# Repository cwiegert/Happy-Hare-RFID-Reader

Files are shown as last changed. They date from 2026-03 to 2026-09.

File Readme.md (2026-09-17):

$$\Huge{\color{red}\textsf{Thanks for landing here!}}$$

$$\LARGE{\color{red}\textsf{The Happy Hare add-on is now base functionality in Happy Hare v4.}}$$

$$\LARGE{\color{red}\textsf{Please go to https://github.com/moggieuk/Happy-Hare for the new install.}}$$

<h3 align="center"><a href="https://github.com/moggieuk/Happy-Hare">➡️ Go to Happy Hare v4 &mdash; github.com/moggieuk/Happy-Hare</a></h3>

> [!CAUTION]
> **This repository is no longer maintained.**
>
> Every capability this add-on provided has been migrated into **Happy Hare v4** as
> a base option. There is nothing here you need any more — install Happy Hare v4
> instead: 
>
> No further fixes, features, or compatibility updates will be published here.
> The content below is kept only as a historical reference for existing installs.
Edit the readme to state this is repo is no longer maintained, and the recommended approach for deploymnet is Happy Hare v4 .   document the capabilitiees have all been migrated to base options in Happy Hare v4.   

_____________________________________________________________________
_____________________________________________________________________
_____________________________________________________________________
> [HISTORICAL NOTES and INSTRUCTIONS]

$$\LARGE{\color{red}\textsf{This repository is not actively maintained}}$$

## Recommended Deployment: Happy Hare v4

**Install [Happy Hare v4](https://github.com/moggieuk/Happy-Hare) and enable NFC/RFID
there.** Do not start a new install from this repository.

NFC spool identification is no longer an add-on that has to be layered on top of
Happy Hare. It ships as part of Happy Hare v4 and is configured through Happy Hare's
own options, so a new install needs one project, one config, and one updater instead
of a plugin tracking a moving host.

### Capabilities Migrated to Happy Hare v4 Base Options

Everything in the table below is now native Happy Hare v4 functionality. Consult the
[Happy Hare v4 documentation](https://github.com/moggieuk/Happy-Hare) for the current
option names and setup steps — the configuration keys documented further down this
page belong to this retired add-on and do not apply to v4.

| Capability this add-on provided | Status in Happy Hare v4 |
|---|---|
| Per-lane NFC readers on lane/EMU MCUs | Base option |
| Single shared reader inside the MMU body (tap before loading) | Base option |
| Hybrid per-lane plus shared reader operation | Base option |
| NFC reader as a virtual homing endstop for scan-jog | Base option |
| Scan-jog spool rotation to find the tag during preload | Base option |
| PN532, PN7160, RC522, and PN5180 reader support | Base option |
| Spoolman UID lookup and gate-map assignment | Base option |
| Rich tag parsing (NTAG/Type-2, MIFARE Classic, SLIX2/ISO15693) | Base option |
| Vendor tag formats (Bambu, Creality, ELEGOO, Anycubic, QIDI, TigerTag, OpenSpool, OpenTag3D, OpenPrintTag) | Base option |
| Spoolman auto-create from tag metadata | Base option |
| Per-gate NFC LED effects | Base option |

### Migrating an Existing Install

1. Read the [Happy Hare v4](https://github.com/moggieuk/Happy-Hare) install and NFC
   documentation first — v4 owns this functionality now, and its options differ from
   the ones described below.
2. Run this repository's `uninstall.sh` to remove the add-on's Klipper extras,
   generated config, and macro includes.
3. Install or update Happy Hare v4 and enable its NFC/RFID options.
4. Re-flash any MCU hosting an NFC reader from the same Klipper checkout, then
   restart Klipper and confirm every MCU reconnects.

---

## Archived Reference

Everything from here down documents the retired add-on. It is preserved for anyone
maintaining an existing installation and is **not** a guide for new deployments.

## Happy Hare RFID/NFC Reader (retired add-on)

NFC spool identification for Happy Hare. Use one NFC reader on each EMU lane, one shared reader inside the MMU body, or both. PN532 remains the default reader; PN7160, RC522, and PN5180 are available with `reader_type: pn7160`, `rc522`, and `pn5180`.

This is a system-level Klipper integration, not a plug-and-play appliance. It touches Klipper extras, Happy Hare macros, lane MCU firmware, I2C wiring, Spoolman, and optional LED effects. If you are not comfortable recovering from a Klipper config error, reflashing lane MCUs, and reading logs, expect a learning curve.

## Why This Project Is Different

Most DIY spool RFID/NFC systems put a small controller such as an ESP32 near the
reader and report tags over WiFi, MQTT, or another side channel. Others wire the
reader back to the host Raspberry Pi, which often means long SDA/SCL or USB runs
through the printer.

This project keeps the reader inside the MMU wiring domain. Each NFC reader is
connected directly to an existing Klipper MCU I2C bus, usually the MMU board or
the per-lane board inside the MMU. Klipper talks to that MCU, and the plugin
integrates the result with Happy Hare and Spoolman.

Practical hardware choices:

- **EMU / one board per lane:** per-lane readers are a natural fit. Each lane has
  its own MCU/I2C bus, so PN532 and PN7160 are both valid choices.
- **Other B-style multi-material systems with one MMU board:** PN7160 is usually
  the better choice for multiple readers on one bus because it has four
  selectable I2C addresses (`40-43` / `0x28-0x2B`). That matches many four-color
  MMU layouts.
- **Single shared reader:** PN532, PN7160, RC522, or PN5180 can be mounted
  inside the MMU body and used as a tap-before-loading reader. PN5180 is the
  SPI option when SLIX2 (ISO15693/Type-5) support is required.

For EMU installations, [`NFC Mounting Bracket/`](NFC%20Mounting%20Bracket/)
contains the printable STL and editable STEP source for the NFC-reader LED holder.

## Virtual Endstop — How Scan-Jog Finds the Tag

Per-lane installs register each lane's NFC reader as a real Klipper/Happy Hare
homing endstop (`mmu_nfc_endstop.py`, `[mmu_nfc_endstop laneN]`) — no extra
hardware or wiring, it borrows the reader the matching `[nfc_gate laneN]`
section already owns. When scan-jog searches for the tag, the forward search
is a genuine Klipper homing move (`ENDSTOP=nfc_lane<N>`) that stops the
instant the tag is detected, instead of jogging a fixed chunk and polling
afterward and hoping the tag was somewhere in that chunk. This is generated
automatically for every enabled lane by `install.sh` — there is nothing extra
to configure. See [How It Works](docs/shared/how-it-works.md) for the full
scan loop and [Configuration Reference](docs/shared/configuration.md) for the
`[mmu_nfc_endstop laneN]` keys.

The same configuration supports Happy Hare V3 and V4. The plugin registers
the software endstop on V3's shared gear rail or on the V4 drive selected by
the reader's `mmu_gate`. Lane and endstop section names are only labels; the
`nfc_gate` reference and `mmu_gate` value provide the actual binding, including
multi-unit installations.

## Operating Modes

| Mode | Hardware | Best For | Flow |
|---|---|---|---|
| Per-lane readers | One NFC reader per EMU gate/lane MCU (default PN532; PN7160, RC522, or PN5180 supported) | Automatic spool identification during lane preload | Load spool -> HH parks filament -> NFC scan-jog rotates spool -> Spoolman lookup -> HH gate map |
| Shared reader | One NFC reader mounted inside the MMU body (PN532, PN7160, RC522, or PN5180) | Fewer readers, manual tap before loading | Tap tag -> spool staged -> load any gate -> HH pregate preload -> staged spool assigned |
| Hybrid | Per-lane readers plus shared reader | Normal lanes with per-lane readers, plus shared/bypass workflows | Lane readers handle scan-jog; shared reader stages tapped spools for preload |

The shared reader can stage only a real Spoolman spool ID. UID lookup, embedded spool IDs, and auto-created Spoolman records work. Metadata-only tags without a Spoolman spool ID cannot be staged for Happy Hare preload.

## Requirements

- Voron/EMU setup running the [igiannakas IG-dev branch of Happy Hare](https://github.com/igiannakas/Happy-Hare/tree/IG-dev), which provides `variable_user_post_preload_extension`
- One Klipper MCU per filament lane for per-lane reader installs, or one MCU hosting the shared NFC reader
- Supported NFC reader hardware configured for its bus
- Hardware I2C or SPI bus on the MCU hosting the NFC reader
- Klipper version requirements:
  - Strongly recommended: use the latest Klipper on the host and every MCU
    hosting an NFC reader. The NFC drivers use Klipper's newer low-level
    `i2c_transfer` / `i2c_bus_status` path so bus errors such as `START_NACK`
    can be handled on the host side instead of turning reader faults into
    Klipper shutdowns.
  - If checking an older install, it should be newer than upstream commit
    `6bbc9069` (`bus: Note mcu code deprecation if missing i2c_transfer`,
    Feb 24, 2026 on GitHub).
  - After updating Klipper, rebuild and flash every MCU hosting an NFC reader.
- Spoolman reachable from the Pi
- NFC tags on spools: NTAG213/215/216, MIFARE Classic, or supported rich-tag formats
- Lane MCU firmware rebuilt from the same Klipper checkout as the host

## Happy Hare V4 Compatibility Notes (retired add-on)

Happy Hare v4 can run the post-preload hook while the MMU reports
`action=checking`. For automatic gate-status polling, NFC treats `checking` as
scan-safe only when the detected Happy Hare major version is 4 or newer. For
the post-preload hook, `_NFC_SCAN_JOG_PRELOAD` sends
`NFC GATE=<n> JOG_SCAN=1 SOURCE=AUTO`; that trusted hook path uses the same
version-aware scan-safe check: Happy Hare v4 accepts `action=idle` or
`action=checking`; Happy Hare v3/pre-v4 and unknown versions accept only
`action=idle`. Manual or console `JOG_SCAN=1` commands without `SOURCE=AUTO`
stay conservative and always require `action=idle`.

Happy Hare V4 also validates `MMU_SET_LED` effect names against its configured
operation effects. NFC therefore starts generated `[mmu_led_effect]` instances
directly on V4, while keeping the existing public `MMU_SET_LED` path on V3.
No LED configuration changes are required: define NFC effects with
`define_on: gates` (or `define_on: gates, exit`) as usual.

Supported readers:

| Reader | `reader_type` | Bus / address | Notes |
|---|---|---|---|
| PN532 | `pn532` | `36` (`0x24`) | Default reader and documented PN532 wiring path |
| PN7160 | `pn7160` | `40-43` (`0x28-0x2B`) | Supports NTAG/Type2, ISO15693/Type5, and authenticated Bambu/MIFARE reads |
| RC522 | `rc522` | SPI (`cs_pin` + `spi_bus`/software SPI pins) | UID lookup, NTAG/Type-2 rich reads, and authenticated MIFARE/Bambu reads; no ISO15693 |
| PN5180 | `pn5180` | SPI (`cs_pin`, `spi_bus`/software SPI pins, `busy_pin`, `reset_pin`) | ISO14443A/NTAG, authenticated MIFARE/Bambu, and SLIX2 (ISO15693/Type-5) reads; see the SLB nine-wire wiring guide |

Supported tag formats:

| Tag / data path | PN532 | PN7160 | RC522 | PN5180 | Notes |
|---|---:|---:|---:|---:|---|
| Spoolman UID lookup | Yes | Yes | Yes | Yes | Default path. The tag only needs a readable factory UID registered in Spoolman's extra field. |
| NTAG / NFC Type 2 rich tags | Yes | Yes | Yes | Yes | NDEF text/URI/MIME/JSON payloads, OpenSpool, OpenTag3D, TigerTag, OpenPrintTag text-compatible payloads, and several manufacturer binary tags. |
| MIFARE Classic rich tags | Yes | Yes | Yes | Yes | Bambu, QIDI Box, and Creality CFS all require `tag_parsing: True` and `bambu_reads: True`. Bambu's own keys and Creality's UID-derived Key B both additionally require `pycryptodome`; QIDI uses a factory-default-key fallback that needs no extra dependency (see [Configuration Reference](docs/shared/configuration.md#tag-data-parsing)). |
| SLIX2 / ISO15693 Type 5 rich tags | No | Yes | No | Yes | Current Type-5 rich-read path is for SLIX2 tags. Its payload enters the normal parser and is not limited to OpenPrintTag. Official OpenPrintTag antenna size is best suited to a shared reader; per-lane use needs hardware testing. |

The vendored parser currently recognizes Bambu Lab, ELEGOO, Anycubic ACE,
TigerTag, Creality CFS/K1/K2, QIDI Box, SimplyPrint/QIDI URL tags, OpenTag3D,
OpenSpool, OpenPrintTag, and generic NDEF JSON filament records. See
[Spoolman Integration](docs/shared/spoolman-integration.md) for format details
and auto-create behavior. Bambu, TigerTag/TigerTag+, and tested Creality
CFS/K1/K2 rich tags also expose parser-derived same-spool `spool_identity`
values for scan-jog left-neighbor interference handling.

## Documentation

| Guide | Purpose |
|---|---|
| [NFC Reader Wiring](docs/i2c-nfc/wiring.md) | PN532, PN7160, RC522, and PN5180 wiring; includes the PN5180 SLB nine-wire guide |
| [Install & Uninstall](docs/shared/install-uninstall.md) | Installer behavior, includes, updates, removal |
| [First-Time Setup](docs/i2c-nfc/setup.md) | Configure Spoolman, lane hardware, first verification |
| [Shared Reader](docs/shared/shared-reader.md) | Shared-reader workflow, hook wiring, commands, LED behavior |
| [Configuration Reference](docs/shared/configuration.md) | Every config key, defaults, inheritance rules |
| [Commands & Macros](docs/shared/klipper-functions.md) | User commands, shared commands, callback macros |
| [Message Definitions](docs/shared/message_definition.md) | Console output and matching `nfc_reader.log` entries |
| [Spoolman Integration](docs/shared/spoolman-integration.md) | Extra field setup, UID registration, lookup behavior |
| [Troubleshooting](docs/i2c-nfc/troubleshooting.md) | Startup errors, reader failures, tag lookup issues |
| [How It Works](docs/shared/how-it-works.md) | Boot sequence, poll flow, scan-jog, dispatch layers |
| [Expert I2C Debugging](docs/shared/expert-low-level-i2c-debugging.md) | Low-level PN532 probe commands |

## Quick Install

Before installing, rebuild and flash Klipper firmware on every MCU that will host an NFC reader. Host and MCU firmware version mismatches produce I2C failures that look like wiring or reader problems.

```bash
cd ~
git clone https://github.com/cwiegert/Happy-Hare-RFID-Reader.git rfid-reader
cd ~/rfid-reader
bash install.sh
```

Beta cutover note: if an old `~/emu-nfc-reader` install exists, the installer prompts before backing it up/removing it and continuing with a fresh `~/rfid-reader` install.

The interactive installer runs once. Normal updates are installed afterward from Moonraker's web interface in Mainsail or Fluidd. If installer-owned links or integration files are damaged, run `bash install.sh -r`; repair does not rewrite user NFC settings. To change the configured reader layout or settings later, run `bash install.sh --reconfigure`; the wizard backs up the complete NFC configuration before applying changes.

The installer adds the matching includes to `printer.cfg` in this order.

Per-lane readers:

```ini
[include nfc/nfc_reader.cfg]
[include nfc/nfc_macros.cfg]
[include nfc/nfc_reader_hw.cfg]
```

Shared-reader-only:

```ini
[include nfc/nfc_reader.cfg]
[include nfc/nfc_macros.cfg]
[include nfc/nfc_reader_shared.cfg]
```

Hybrid:

```ini
[include nfc/nfc_reader.cfg]
[include nfc/nfc_macros.cfg]
[include nfc/nfc_reader_hw.cfg]
[include nfc/nfc_reader_shared.cfg]
```

The installer sets Spoolman in `~/printer_data/config/nfc/nfc_reader.cfg`; verify the selected value after installation:

```ini
[nfc_gate]
spoolman_url:      auto
spoolman_rfid_key: rfid_tag
```

Choose the Happy Hare post-preload hook that matches the reader layout:

```ini
[gcode_macro _MMU_SEQUENCE_VARS]
# Shared reader only:
variable_user_post_preload_extension: '_NFC_SHARED_PRELOAD'

# Per-lane and shared readers together:
# variable_user_post_preload_extension: '_NFC_HYBRID_PRELOAD'
```

Restart Klipper and run the doctor:

```bash
sudo systemctl restart klipper
```

```gcode
NFC_DOCTOR
NFC_STATUS
```

## Common Commands

```gcode
NFC_HELP                                      ; show normal command help
NFC_HELP ADVANCED=1 CALLBACKS=1 LOW_LEVEL=1  ; show the full command set
NFC_DOCTOR                                   ; check common config/setup problems
NFC_STATUS                                   ; show every configured lane/shared reader
NFC_REGISTER UID=04A1B2C3D4 SPOOL_ID=123     ; link a known UID to an existing Spoolman spool
NFC_LED_TEST ALL=1 CYCLES=2                  ; chase-test lane tag-read LEDs on all enabled lanes
NFC GATE=0 INIT=1                            ; re-run reader init on one lane reader
NFC GATE=0 SCAN=1                            ; raw UID scan, no Spoolman/HH dispatch
NFC GATE=0 LED_TEST=1 CYCLES=2               ; test lane tag-read LED on one gate
NFC GATE=0 POLL=1                            ; read, resolve, and dispatch once
NFC GATE=0 JOG_SCAN=1                        ; run scan-jog manually; blocked if HH gate is empty
NFC GATE=0 READ=1                            ; start lane background polling
NFC GATE=0 READ=0                            ; stop lane background polling
NFC_SHARED STATUS=1                          ; show shared-reader state
NFC_SHARED READ=1                            ; start shared-reader polling
NFC_SHARED REPLACE=1                         ; discard staged shared spool and scan another
NFC_SHARED CANCEL=1                          ; cancel staged shared spool
```

## Key Defaults

These are the defaults shipped in `config/nfc_reader.cfg`:

| Setting | Default | Notes |
|---|---:|---|
| `startup_polling` | `-1` | Lane polling is manual by default; post-preload scan-jog does not need it |
| `poll_interval` | `10` | Per-lane background poll interval in seconds |
| `absent_threshold` | `3` | Missed polls before a removal event |
| `scan_enabled` | `False` | Disables automatic gate-status scan-jog trigger; manual/hook `JOG_SCAN` still works |
| `scan_jog_mm` | `150.0` | Logical scan chunk divided into three stopped-position substeps |
| `scan_jog_max` | unset | Optional fixed scan-jog travel limit; leave unset to use the lane Bowden length |
| `scan_reads_per_position` | `1` | Reads per stopped scan position |
| `scan_poll_interval` | `0.25` | Read spacing during scan-jog and shared-reader polling cadence |
| `scan_motion_mode` | `continuous` | `continuous` homes the forward search against the lane's virtual NFC endstop, stopping the instant the tag is detected; `stopped` keeps blocking substep reads |
| `scan_continuous_step_mm` | `150.0` | Continuous-mode forward chunk size. Rich reads use the observed UID hit-window center, so this no longer needs to be kept small for rich-tag positioning |
| `scan_continuous_speed` | `200.0` | Continuous-mode gear move speed |
| `scan_continuous_accel` | `2000.0` | Continuous-mode gear move acceleration |
| `scan_continuous_poll_interval` | `0.05` | In-flight NFC read cadence while a continuous chunk is estimated to be moving |
| `debug` | `2` | Warnings and errors in `nfc_reader.log` |
| `console_output` | `False` | Keep routine NFC logs out of the console |

To try continuous scan-jog:

```ini
[nfc_gate]
scan_motion_mode: continuous
scan_continuous_step_mm: 150.0
scan_continuous_speed: 200.0
scan_continuous_accel: 2000.0
scan_continuous_poll_interval: 0.05
```

Continuous mode preserves the existing tag-found flow: the read-light effect
plays for about 0.1 second, then NFC rewinds and dispatches the cached tag/spool
action just like stopped mode.
If a UID is found during motion, continuous mode waits for the current chunk to
finish and checks Spoolman first. If rich tag parsing is still needed, NFC
recenters to the observed UID hit-window center before running rich parsing and
the normal rich-read retry sweep.

Set `enabled: False` on a `[nfc_gate laneN]` or `[nfc_gate shared]` section to keep the config block in place without initializing hardware or registering commands for that reader.

## MCU Firmware Warning

The NFC reader driver talks to firmware running on the MCU, not only to Klipper on the Pi. After updating Klipper, rebuild and flash every lane/shared MCU that hosts an NFC reader before debugging NFC.

Recommended update order:

```text
1. Update the Klipper host checkout.
2. Build MCU firmware from that same checkout.
3. Flash every MCU that hosts an NFC reader.
4. Restart Klipper.
5. Confirm all MCUs reconnect before testing NFC.
```

When host and MCU firmware are out of sync, common symptoms include reader init failures, `i2c_read_response` timeouts, and other devices on the same I2C bus failing unexpectedly.

## License

Copyright (C) 2026 WoodWorker.
Licensed under [GNU General Public License v3.0 or later](https://www.gnu.org/licenses/gpl-3.0.html).
See [LICENSE](LICENSE) for the full terms.

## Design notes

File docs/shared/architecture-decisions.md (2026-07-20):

# Architecture Decisions

[← Back to README](../../Readme.md)

---

This document captures the design decisions made while building the PN532 I2C path, including the reasoning and trade-offs behind each choice. It is meant to explain *why* the system is structured the way it is — so that future changes can be made with the context that drove the original decisions.

---

## Decision: Strict Layer Ownership

**What we decided:** Each layer owns exactly one responsibility and may not reach across its boundary into another layer's domain.

| Layer | Owns | Explicitly does not own |
|---|---|---|
| `PN532Driver` | PN532 wire protocol, I2C frames, UID extraction | Spoolman, gate policy, Happy Hare commands |
| `SpoolmanClient` | UID → spool record lookup and cache | Gate state, lane assignment, MMU commands |
| `NFC_Manager` | Gate state machine, changed/removed decisions, macro dispatch | PN532 protocol details |
| `nfc_macros.cfg` | Happy Hare-facing GCode calls | NFC bus reads, Spoolman HTTP requests |

**Why:** The alternative was a flat design where one module reads the tag, queries Spoolman, and calls `MMU_GATE_MAP`. We rejected this because it creates a single module that breaks for three independent reasons: hardware issues, Spoolman API changes, and Happy Hare version differences. Each layer now has a single reason to change.

**The boundary that matters most:** `SpoolmanClient` never calls Happy Hare. `PN532Driver` never calls Spoolman. NFC_Manager is the only module that sees both a UID and a gate assignment, and it dispatches a macro rather than calling Happy Hare directly.

---

## Decision: Tags Are Read-Only — UID Lookup Only

**What we decided:** The system reads the factory UID only. Tags are never written to. The UID is stored as a Spoolman extra field on the spool record.

**Why we rejected writing tags:** Writing tag payload data would require:
- A tag format standard (which format? which pages? how versioned?)
- A tag programming workflow for users
- Handling format mismatches on old tags after upgrades
- Dealing with write failures and partially-written tags

The UID approach requires none of this. Any blank NFC sticker from any supplier works. The spool association is managed entirely in Spoolman. If you need to associate a different spool with a tag, you update one extra field in Spoolman — the tag is unchanged.

**Trade-off accepted:** The tag must be registered in Spoolman before it can resolve to a spool. An unregistered tag produces `_NFC_TAG_NO_SPOOL` instead of silently failing.

---

## Decision: SpoolmanClient Is a Pure Lookup Client

**What we decided:** SpoolmanClient resolves UID → spool record and caches results. It does not PATCH Spoolman location, and it does not call `MMU_GATE_MAP`, `MMU_SPOOLMAN`, or any Happy Hare command.

**Why:** The gate a spool belongs to is a *physical fact*, not a Spoolman record fact. Spoolman knows spool IDs and filament metadata. It does not know the MMU gate layout. The thing that knows both a spool ID and a gate number is NFC_Manager — and that is exactly where the gate assignment decision lives.

Keeping Happy Hare commands and gate-aware Spoolman writes out of SpoolmanClient means it can still be used from any context where you have a UID and need a spool ID. Happy Hare owns gate map state and synchronizes that state to Spoolman via `MMU_SPOOLMAN SYNC=1 QUIET=1` in `nfc_macros.cfg`.

---

## Decision: Happy Hare Calls Are Behind `_NFC_*` Macros

**What we decided:** NFC_Manager dispatches three GCode macros. Those macros call `MMU_GATE_MAP` for Happy Hare runtime state and pass `SYNC=1` when we want Happy Hare to synchronize the gate map to Spoolman. NFC_Manager does not call Happy Hare commands directly.

```
NFC_Manager → _NFC_SPOOL_CHANGED GATE=n SPOOL_ID=id UID=uid
           → _NFC_SPOOL_REMOVED  GATE=n
           → _NFC_TAG_NO_SPOOL   GATE=n UID=uid

nfc_macros.cfg → MMU_GATE_MAP GATE={gate} SPOOLID={spool_id} AVAILABLE=1 SYNC=1 QUIET=1
```

**Why:** Happy Hare's GCode API evolves between versions. The exact command for "tell Happy Hare about this spool" belongs in editable GCode config, not Python. The default macro is designed for Happy Hare `spoolman_support: push`: `MMU_GATE_MAP` sets the local runtime gate map and `SYNC=1` lets Happy Hare synchronize that local map to Spoolman. NFC_Manager already knows the physical gate that produced the read, so it passes both `GATE` and `SPOOL_ID` into the macro boundary.

This also makes the integration boundary visible. Anyone debugging a Happy Hare integration problem knows to look in `nfc_macros.cfg` — not in `pn532_driver.py`.

**Corollary:** If a Happy Hare version requires a different synchronization command, adjust `nfc_macros.cfg`. Do not add it to `PN532Driver` or `SpoolmanClient`.

**Exception — scan-jog's motion path:** `scan_jog.py` calls Happy Hare's Python
motion API directly in several places (`mmu.move_filament()`,
`mmu.select_gate()`, `mmu._initialize_filament_position()`/
`initialize_filament_position()`), rather than going exclusively through
gcode macros. Motion needs return values on the same call — actual distance
homed, whether the move triggered an endstop — that a fire-and-forget gcode
macro dispatch can't hand back cleanly, and gate selection specifically needs
to avoid `cmd_MMU_SELECT`'s own unconditional console print (see
`select_gate_quiet()`). Every direct call has a gcode fallback
(`_MMU_STEP_HOMING_MOVE`, `_MMU_STEP_MOVE`, `MMU_SELECT`) for Happy Hare
installs that don't expose the Python method, so the version-fragility this
decision is meant to avoid is still contained — just pushed into a
`hasattr()` check in `scan_jog.py` instead of a macro file.

---

## Decision: Removal Is Debounced

**What we decided:** A single missed read does not declare a spool removed. The gate must be absent for `poll_interval × absent_threshold` seconds before `_NFC_SPOOL_REMOVED` fires.

Default:
```ini
poll_interval:    30   # seconds
absent_threshold: 3    # consecutive missed reads
# ≈ 90 seconds before removal fires
```

**Why:** NFC reads can miss for reasons that have nothing to do with spool removal: tag angle, distance, vibration, RF interference from steppers, or a single delayed I2C transaction. If removal fired on every miss, a spool sitting in a gate would trigger constant remove/detect cycles during a print.

90 seconds of absence is unambiguous. If a spool is physically gone, 90 seconds is fast enough to be useful. If it was a transient read miss, it recovers on the next successful poll.

---

## Decision: Per-Lane I2C Bus (One PN532 Per EBB42)

**What we decided:** Each per-lane gate reader has one PN532, wired to the I2C
bus on that lane's EBB42. There is no shared I2C bus across the lane readers.

**Why we chose this over a shared bus / multiplexer:**
- No I2C address management. Every PN532 can stay at `0x24` because they are on separate buses.
- No multiplexer hardware (`TCA9548A` or similar) to buy, wire, or configure.
- Failures are isolated. A PN532 that holds SDA low only affects one lane.
- The lane MCU already exists as part of the Happy Hare hardware setup. Its I2C bus is available with no extra wiring effort.

**Trade-off accepted:** The per-lane reader design only works when each lane has
its own MCU. A printer with a single MCU for all lane readers would need a
different approach (multiplexer or shared bus with unique addresses).

**Shared-reader exception:** The optional shared reader is not part of the
per-lane reader set. It is a single PN532 mounted inside the MMU body and wired
to whichever MCU hosts that I2C bus. It stages `NEXT_SPOOLID` for Happy Hare
instead of assigning a physical lane directly. See
[Shared Reader](shared-reader.md).

---

## Decision: NFC_Manager Owns the Baseline Startup Policy

**What we decided:** On startup, NFC does not blindly overwrite Happy Hare's gate map with whatever the readers see at boot time.

**Why:** Happy Hare already starts with a known gate/filament map from its own config and persisted state. Tags may not be physically near readers at startup. A spool may be in a gate but temporarily unreadable. If NFC declared every gate empty on boot and then started filling them in as reads succeed, it would create a noisy burst of `MMU_GATE_MAP ... SYNC=1` updates during Klipper startup.

**Current implication:** NFC_Manager treats reads as events (state changes), not as complete authority over the gate map. It updates Happy Hare when something changes, not when it confirms that the gate is in the state it was already in.

**Future work:** A proper baseline sync — querying Happy Hare state at startup and comparing it with what the readers see — is the right long-term approach. This would let NFC detect discrepancies between persisted state and physical reality after a power cycle.

---

## Decision: Expert I2C Debug Commands Are Hidden by Default

**What we decided:** The low-level PN532 bus commands (`STEP=`, `RAW_READ`, `RAW_WRITE`, etc.) are not available unless `low_level_debug: True` is set explicitly.

**Why:** Raw bus commands can disturb the PN532 state machine. Sending `PASSIVE_WRITE` without following up with `PASSIVE_ACK` and `PASSIVE_RESPONSE` leaves the PN532 waiting for a read that never comes, which can cause subsequent normal polls to fail until the reader is reinitialized. These commands are useful for bring-up diagnostics but would be confusing and dangerous in normal operation.

Gating them behind a config flag means they are discoverable for bring-up but cannot be called accidentally.

---

## Decision: Python Extras Are Symlinked, Not Copied

**What we decided:** `install.sh` creates symlinks from Klipper's extras directory into the repo clone. It does not copy files.

**Why:** If files were copied, every update would require running `install.sh` to copy the new versions. With symlinks, Moonraker can update the Git checkout from its web interface and Klipper reads the updated Python files after Moonraker restarts it. The interactive installer does not run during normal updates.

**Implication:** The repo clone must remain present on the Pi. If the repo is deleted, the symlinks break and Klipper will fail to start.

---

## Decision: User Config Is Preserved; Interface Macros Are Read-Only

**What we decided:** `install.sh` creates user configuration once. A completed installation does not rerun interactive setup, and `install.sh -r` repairs only installer-owned integration files. An explicit `--reconfigure` path backs up the complete NFC configuration before rerunning the wizard. `nfc_macros.cfg` is read-only because it defines the NFC reader's interface to Happy Hare.

**Why:** Reader and hardware files contain machine-specific settings. Rewriting them during a software update or repair could destroy working local configuration. The interface macros need to track the installed code and therefore update through their link.

New optional settings must have working code defaults so existing configurations remain valid. Structural migrations, if ever required, must be explicit and backed up rather than hidden inside a normal web update.

---

## Decision: NFC Tag Detection Is a Klipper Homing Endstop, Not a Poll Loop

**What we decided:** Per-lane scan-jog's forward search does not jog a fixed
distance and then poll the reader to see if it got lucky. `mmu_nfc_endstop.py`
registers the lane's existing NFC reader as a real Klipper/Happy Hare
gear-rail endstop (`ENDSTOP=nfc_lane<N>`), and the forward search is a genuine
homing move against it — Klipper's own homing machinery stops the move the
instant the endstop trips, using the same mechanism a physical limit switch
would.

**Why:** A jog-then-poll loop only ever knows the tag was "somewhere in the
last chunk" — the actual position is an estimate reconstructed from move
timing and speed/accel profiles after the fact (see
`homing_distance_from_elapsed`/`corrected_homing_actual` in `scan_jog.py`,
still used as a fallback when the direct Happy Hare motion API isn't
available). A homing move reports the real, physically-measured trigger
position directly from Klipper's stepper/endstop code — the same accuracy
guarantee any other homed axis gets. Continuous mode's UID hit-window
recentering before rich tag parsing exists specifically to correct for the
residual uncertainty of *where within the tag's read range* it triggered, not
to compensate for chunk-boundary guessing.

**How it works:** `mmu_nfc_endstop.py` implements Klipper's standard MCU
endstop interface (`home_start`/`home_wait`/`query_endstop`/`get_steppers`).
It does not add any new hardware or wiring — `home_start()` just starts a
reactor timer that polls the *same* reader object the matching `[nfc_gate
laneN]` section already owns, at `poll_interval` (default `0.05s`), and calls
back into Klipper's homing completion the moment a read succeeds.

**Trade-off accepted:** The endstop's trigger latency is bounded by
`poll_interval`, not by hardware response time like a real switch. At the
default `0.05s` and typical scan speeds this is well inside the reader's own
practical read-range tolerance, but it means homing accuracy here is
software-timed, not electrically-timed — worth knowing if `poll_interval` is
tuned much higher.

**Corollary:** `[mmu_nfc_endstop laneN]` requires its matching `[nfc_gate
laneN]` to be enabled with a working reader at Klipper connect time — it
raises a config error rather than silently no-op'ing if the lane is disabled,
so both sections must be enabled or disabled together.

---

## Boundary Summary

```
┌─────────────┐    UID only    ┌──────────────────┐   spool_id    ┌────────────────┐
│ PN532Driver │ ─────────────► │   NFC_Manager    │ ────────────► │ SpoolmanClient │
│             │                │                  │               │                │
│ I2C frames  │                │ gate state       │               │ UID lookup     │
│ UID extract │                │ changed/removed  │               │ cache          │
└─────────────┘                │ macro dispatch   │               └────────────────┘
                               └────────┬─────────┘
                                        │ _NFC_SPOOL_CHANGED
                                        │ _NFC_SPOOL_REMOVED
                                        │ _NFC_TAG_NO_SPOOL
                                        ▼
                               ┌─────────────────┐
                               │  nfc_macros.cfg  │
                               │                  │
                               │  MMU_GATE_MAP    │
                               │  MMU_SPOOLMAN    │
                               │  (Happy Hare)    │
                               └─────────────────┘
```

No layer reaches back up the stack. No layer reaches sideways. The only direction is down and out through the macro boundary.

---

*Copyright (C) 2026 WoodWorker. Licensed under [GPL-3.0-or-later](https://www.gnu.org/licenses/gpl-3.0.html) — see [LICENSE](../../LICENSE).*

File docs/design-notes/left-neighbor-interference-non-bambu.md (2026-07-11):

# Design Note: Left-Neighbor Interference Detection for Non-Bambu Rich Tags

Status: **Design only — not yet implemented.**

---

## Background

`scan_jog.py`'s left-neighbor interference mitigation currently only fires
for Bambu-format tags. `is_left_neighbor_spool_identity_match()`
(`scan_jog.py:1545`) compares `current_tag.spool_identity` between the
scanning gate and its immediate left neighbor's cached tag — and
`spool_identity` is only ever set by the Bambu block parser
(`vendor/rfid_tag_parser.py:846`, `"bambu_%s" % tray_uid`). No other format
in the vendored parser sets it, and `_spool_identity_from_meta()`
(`tag_handler.py:232`) has no fallback field.

This wasn't an oversight — commit `3484a95` ("Use spool identity for
left-neighbor interference", jacksky6) deliberately replaced an earlier
UID-based check specifically because Bambu spools carry **two physical NFC
tags, one per side, each with a different chip UID** for the same spool. A
straight UID comparison couldn't recognize those as the same spool, so the
fix switched to the tray-embedded `spool_identity`, which is identical on
both side-tags. The commit is explicit that this was a deliberate,
Bambu-scoped decision: *"There is intentionally no UID, Spoolman, material,
color, or Happy Hare metadata fallback."*

The gap: every other supported format — ELEGOO, Anycubic ACE, TigerTag,
Creality CFS/K1/K2, QIDI Box, OpenTag3D, OpenSpool, OpenPrintTag, generic
NDEF JSON — gets **no** interference protection at all today.

## What the research shows about other formats

Checked against both the vendored parser's actual field output and the
public specs for the open standards this project supports:

| Format | Physical tags per spool | Fields the parser extracts | Per-spool instance ID in the payload? |
|---|---|---|---|
| **Bambu** | 2 (different chip UIDs) | material, brand, color, temps, `tray_uid` | **Yes** — `tray_uid` (hence `spool_identity`) |
| ELEGOO | 1 | material, brand, color_hex, diameter_mm, weight_g | No |
| Anycubic ACE | 1 | brand, material, sku, color_hex, temps, diameter_mm | No — `sku` is a catalog/product code, identical across every spool of that product |
| Creality CFS/K1/K2 | 1 | material, brand, color_hex | No |
| QIDI Box | 1 | material, brand, color_hex, diameter_mm | No |
| TigerTag | 1 | material, brand, temps, fabrication timestamp | No — the tag's own NFC chip UID *is* presented as "the unique ID" per TigerTag's own docs |
| OpenSpool | 1 | type (material), color_hex, brand, temps | No |
| OpenTag3D | 1 | manufacturer, material, color, print settings | No (spec still finalizing, no per-unit ID field documented) |
| OpenPrintTag | 1 | material, color, weight, temps, density, diameter | No — per OpenPrintTag's own materials: *"the tag itself stores only a UID, which serves as the unique identifier for each tag"* |

Two findings that matter for this design:

1. **Bambu's dual-tag-per-spool design looks like the outlier, not the norm.**
   Every other researched format is one physical NFC chip per spool. For
   those, the chip's own factory UID reliably and persistently identifies
   that specific physical spool — which is exactly the property `spool_identity`
   was invented to provide for Bambu's two-tags-one-spool case.
2. **None of the researched metadata fields are per-instance.** Material,
   color, brand, and even SKU are all *product-catalog* attributes — the
   same for every spool of that product, not a serial number for one
   physical unit. Two different spools of, say, the same Anycubic PLA Black
   SKU would produce **identical** metadata.

## Implication for the original ask

The original ask was: read the rich tag on a non-Bambu format, compare its
parsed metadata against what's cached for the left neighbor, and treat a
match as proof of interference. Given finding (2) above, that check alone
has a real false-positive mode: two genuinely different spools of the same
product in adjacent gates (a common real scenario — buying more than one
spool of a popular color) would match on metadata despite not being the
same physical spool at all, and `shift_left_neighbor()` would then jog the
left gate's own, correctly-loaded spool out of position for no reason.

Given finding (1), there's a lower-risk option available for every
single-tag format: fall back to comparing the raw NFC UID itself, restoring
(in scoped form) the mechanism `3484a95` removed wholesale. For a
single-tag-per-spool format, gate N genuinely reading gate N-1's antenna
field means gate N's reader is picking up **the exact same physical chip**
— so its UID will exactly match gate N-1's cached UID. This has no
metadata-collision failure mode, costs nothing extra to compute (the UID is
already read every poll), and directly mirrors why `spool_identity` works
for Bambu — both are "the identifier that's actually invariant for this
physical spool," just sourced differently per tag design.

## Proposed design: tiered identity check

Generalize `current_spool_identity()` into something that returns a
`(tier, value)` pair instead of a single Bambu-only string, and only ever
compare values within the same tier (never let a UID-tier value match
against a metadata-tier value, and never let either match against a
`spool_identity`-tier value):

```
Tier 1 — spool_identity   (existing, Bambu only, unchanged)
Tier 2 — raw NFC UID       (new: any format, when spool_identity is absent)
Tier 3 — metadata fingerprint (new: opt-in, only when even the UID
                                comparison isn't decisive — see caveat below)
```

```python
def current_spool_signature(gate):
    tag = gate._state.current_tag
    if tag is None:
        return None
    if getattr(tag, 'spool_identity', None):
        return ('identity', tag.spool_identity)          # Tier 1
    if getattr(tag, 'uid', None):
        return ('uid', tag.uid)                           # Tier 2
    return None
```

`spool_identity_for_gate()`'s left-neighbor lookup generalizes the same
way, reading the left gate's cached `current_tag` and producing the same
kind of `(tier, value)` pair. `is_left_neighbor_spool_identity_match()`
becomes a same-tier comparison: `mine == left and mine[0] == left[0]`.

**Tier 2 (UID) is the recommended addition.** It closes the real gap (every
non-Bambu format currently gets zero protection) without introducing the
false-positive mode metadata matching has. It's also nearly free to add: the
existing `read_uid_from_scan_event()`/`GateState.current_tag` plumbing
already carries the UID everywhere `spool_identity` is read from today.

**Tier 3 (metadata fingerprint) is the part of the original ask this design
flags rather than just building as specified.** Given Tier 2 already covers
the true RF-crosstalk case for every single-tag format (gate N reading gate
N-1's actual chip means an exact UID match, full stop), Tier 3 adds
detection power only for a narrower, harder-to-justify case — e.g., a
physical tag that was replaced/rewritten on the same spool, so the UID
changed but the printed contents (material/color/brand) didn't. If it's
still wanted despite the collision risk:

- Build the fingerprint from the *most* discriminating fields available,
  not material+color alone — `sku`/`material_id`/`material_variant_id` when
  present, combined with material+color+brand+diameter+weight when they
  aren't, all case-normalized and joined into one string.
- Require an exact match on the *entire* available field set, not a partial
  overlap — partial matches only make the collision problem worse.
- Consider making a Tier 3 match **log a warning and stop the scan for
  manual confirmation** rather than automatically triggering
  `shift_left_neighbor()`'s physical jog, since a wrong automatic shift
  moves a correctly-loaded neighbor spool out of position. Tier 1 and 2
  matches are exact-identity proofs and are safe to act on automatically;
  Tier 3 is a heuristic and arguably shouldn't drive an unattended physical
  move by itself.

This is the one part of this design that's a genuine open question rather
than a settled recommendation — worth your call before it's built.

## Integration points (unchanged from the existing mechanism)

No new hooks needed — `handle_left_neighbor_interference()`
(`scan_jog.py:1650`), `shift_left_neighbor()`, and `restore_left_neighbor()`
keep their current structure and call sites. Only the identity computation
and comparison (`current_spool_identity()` /
`is_left_neighbor_spool_identity_match()`) change shape, from a single
Bambu-only string to the tiered `(tier, value)` check above. The retry/abort
state tracking (`_scan_left_neighbor_identity`, capped at
`LEFT_NEIGHBOR_CLEARANCE_RETRIES` attempts) stays as-is, just now populated
from whichever tier produced the match.

## Suggested implementation sequence

1. Generalize `current_spool_identity()` → `current_spool_signature()`
   returning `(tier, value)`, adding the Tier 2 UID fallback.
2. Generalize `spool_identity_for_gate()` the same way for the left
   neighbor's cached tag.
3. Update `is_left_neighbor_spool_identity_match()` to compare same-tier
   pairs only.
4. Decide on Tier 3 (build it with the log-and-stop behavior above, or skip
   it and rely on Tier 1 + Tier 2) — this needs a decision before
   implementation, not just a default choice.
5. Update `docs/shared/architecture-decisions.md` / test coverage
   (`tests/test_scan_jog_mode.py` per `3484a95`'s precedent) to cover the
   new UID-tier case explicitly, including a same-product-different-spool
   test proving Tier 3 (if built) doesn't fire on metadata alone without an
   identity or UID match.

## Sources

- [TigerTag-Project/TigerTag-RFID-Guide](https://github.com/TigerTag-Project/TigerTag-RFID-Guide) — TigerTag data structure; unique ID is the tag's own serial
- [TigerTag.io](https://tigertag.io/) — "Every NFC tag has a unique ID (serial number)... Each spool carries a unique identifier" (chip-level, not a separate payload field)
- [OpenSpool (spuder/OpenSpool)](https://github.com/spuder/OpenSpool) — JSON payload fields: protocol, version, type, color_hex, brand, min_temp, max_temp
- [OpenTag3D specification](https://opentag3d.info/spec.html) — NTAG213/215/216, manufacturer/material/color/print-settings fields, spec still finalizing (v0.020 at time of writing)
- [OpenPrintTag.org](https://openprinttag.org/) — CBOR payload on ISO15693 tags; "the tag itself stores only a UID, which serves as the unique identifier for each tag"
- [SimplyPrint: All about NFC/RFID for filament spools](https://help.simplyprint.io/en/article/all-about-nfc-rfid-for-filament-spools-bambu-openprinttag-creality-qidi-anycubic-more-19luyni/) — general survey confirming per-format data varies but per-spool distinction commonly relies on the chip's own unique ID

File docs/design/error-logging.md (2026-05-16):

# Design: Error Handling and Logging

> Engineering reference — not end-user documentation.

---

## Log Architecture

The NFC system uses a dedicated logger named `nfc_gate` separate from the main Klipper logger. It writes to `nfc_reader.log` in the same directory as `klippy.log`.

```python
# log.py — module-level singleton created at import time
logger = _build_logger()
```

`_build_logger()` creates the logger, attaches `_DateRotatingFileHandler` and `_KlippyForwardHandler`, sets level to `DEBUG` (all messages pass through; the per-instance `debug` integer guards in application code control what gets emitted), and sets `logger.propagate = False`.

`propagate = False` prevents the standard Python propagation chain. Klippy routing is instead handled by `_KlippyForwardHandler`, a second handler attached to the `nfc_gate` logger that selectively forwards records to the root logger (klippy.log):

```python
class _KlippyForwardHandler(logging.Handler):
    def emit(self, record):
        if record.levelno < logging.WARNING:
            return          # INFO and DEBUG stay in nfc_reader.log only
        logging.getLogger().handle(record)   # WARNING+ → klippy.log
```

This means **any** `logger.warning()` or `logger.error()` call anywhere in the package automatically appears in both logs — no special wrapper function required. `logger.info()` and `logger.debug()` calls go to `nfc_reader.log` only.

```python
# Goes to nfc_reader.log ONLY (INFO level):
logger.info("nfc_gate: [%s] Spoolman→spool_id=%s", name, spool_id)

# Goes to nfc_reader.log AND klippy.log (WARNING level):
logger.warning("nfc_gate: [%s] Spoolman unreachable: %s", name, e)

# Goes to nfc_reader.log AND klippy.log (ERROR level):
logger.error("nfc_gate: [%s] PN532 did not respond — check wiring", name)
```

The module-level `info()`, `warning()`, `error()` wrapper functions in `log.py` are kept for call-site compatibility but are now thin aliases to `logger.*` — the handler does all routing.

The `configure()` function in `log.py` is called by `NFCGateDefaults.__init__` and optionally by `NFCGate.__init__`. It replaces the file handler with the configured path and sets up the optional console handler.

---

## Log File Rotation

The file handler is `_DateRotatingFileHandler`, not Python's standard `RotatingFileHandler` (which rotates by file size). This is a custom date-based rotation:

- **Rotates on day advance**: on each `emit()`, the current date is compared to the date of the first entry in the open log file. When the day has advanced, the file is closed, renamed to `nfc_reader.log.YYYY-MM-DD` (using the date from its first entry), and a fresh file is opened.
- **Startup rotation**: at handler construction time, if the existing `nfc_reader.log` contains entries from a prior day, it is immediately rotated before opening a new file. This handles Klipper restarts that happen after midnight.
- **Archive pruning**: after each rotation, old archives are deleted if there are more than 7 or if the archive is older than 7 days. The cutoff date is read from the archive filename, not filesystem mtime.
- **No size limit**: a single day's log file can grow arbitrarily large. Tune `debug` level if log volume is a concern.

Log line format (set by `_LOG_FORMATTER`):

```
2026-04-20 14:32:01 INFO     nfc_gate: [lane0] gate 0 — tag read uid=A3F200CC
2026-04-20 14:32:01 DEBUG    nfc_gate: [lane0] POLL  gate=0   tag=A3F200CC           →  quiet  (spool=42, uid unchanged)
2026-04-20 14:32:31 INFO     nfc_gate: [lane0] gate 0 — spool confirmed by NFC and HH; suspending scan
```

Format: `YYYY-MM-DD HH:MM:SS LEVEL    message`. The level field is left-padded to 8 characters.

---

## Debug Levels

| Level | Value | What is logged | nfc_reader.log | klippy.log |
|---|---|---|---|---|
| None | `0` | Nothing | — | — |
| Errors | `1` | Init failures, hardware errors, I2C errors | ✅ | ✅ |
| Warnings | `2` | Unexpected conditions, config problems, lifecycle warnings **(default)** | ✅ | ✅ |
| Integration | `3` | Spoolman lookups, HH gate sync, dispatch decisions, cache hits, scan mode start/success/deferred | ✅ | ❌ |
| Trace | `4` | Full I2C frame trace, every byte, every poll event, per-jog-step scan progress | ✅ | ❌ |

`debug` accepts **integers only** (0–4). It is read with `config.getint()` so string values like `debug: info` are rejected. The `console_log_level` parameter accepts both integers and strings (`error`, `warning`, `info`, `debug`).

The `debug` integer is an application-layer gate — code uses guards like `if self._debug >= 3: logger.info(...)`. The Python logger itself is always set to `DEBUG` (passes everything). The `_KlippyForwardHandler` does the sink routing: `WARNING+` records reach klippy.log, `INFO` and `DEBUG` records stay in nfc_reader.log only.

**For normal printing:** `debug: 2`. Warnings and errors only. Minimal file volume.
**During setup / testing scan-jog:** `debug: 3`. Spoolman lookups, HH sync events, scan start/success visible without per-poll noise.
**Diagnosing I2C problems or scan-jog step detail:** `debug: 4`. Every I2C byte logged; each jog step distance logged.

---

## Console Output

When `console_output: True`, NFC log messages at or above `console_log_level` are sent to the Fluidd/Mainsail GCode console.

**Errors are always sent to the console** regardless of `console_output` setting, once the `gcode` object is available. This is unconditional in `_respond_to_console()`:

```python
if record.levelno < logging.ERROR:
    if not _console_enabled or record.levelno < _console_level:
        return  # filtered
# ERROR-level and above: always fall through
```

Console output uses `reactor.register_callback()` to send the message on the reactor thread, avoiding thread-safety issues with `respond_info()`.

The console handler is a `_GCodeConsoleHandler` attached to the `nfc_gate` logger. Its `emit()` delegates to `_respond_to_console()`. The handler is added once and never removed — `configure_console()` checks for its presence before adding.

---

## Error States

### `_failed` Flag

`NFCGate._failed` is set to `True` when the PN532 does not respond during `_delayed_init`:

```python
def _delayed_init(self, eventtime):
    try:
        self._reader.init()         # GetFirmwareVersion with retries, then SAMConfig
        if self._reader.is_alive():
            self._failed = False
            logger.info("nfc_gate: [%s] PN532 reader OK", self._name)
        else:
            self._failed = True
            logger.error("nfc_gate: [%s] PN532 did not respond — check wiring", ...)
    except Exception as e:
        self._failed = True
        logger.error("nfc_gate: [%s] init error: %s", self._name, e)
```

When `_failed` is True:
- `_poll_timer_event` sets `_polling = False` and returns `NEVER` — timer parks, polling stops
- `_set_reading(enabled=True)` refuses to start and prints a console message
- `NFC_STATUS` shows `READER FAILED (check wiring, address 0x24)`
- `_seed_cache_from_hh()` is skipped (only called if `not self._failed`)

Recovery: `NFC GATE=n INIT=1` calls `_manual_init()`, which clears `_failed` and re-runs `reader.init()` + `reader.is_alive()`. If the reader responds, the gate is back to normal and `READ=1` can start polling.

`_failed` is not set by poll errors — only by explicit `init()` failure. A failed init indicates the hardware is absent or mis-wired (persistent). Poll errors may be transient.

### Poll Error Handling

All exceptions that escape `_poll()` are caught in the timer callback:

```python
def _poll_timer_event(self, eventtime):
    ...
    try:
        self._poll()
    except Exception:
        logger.exception("nfc_gate: [%s] poll error", self._name)
    return self.reactor.monotonic() + self._poll_interval
```

`logger.exception()` logs the full Python traceback automatically. Polling continues on schedule — the timer reschedules normally. Note that this handler is a safety net for the Spoolman and state-machine code paths. It does not fire for PN532 I2C errors because `read_tag()` catches those internally (see below).

### PN532 Hardware Disconnect Mid-Session

`read_tag()` catches all exceptions internally and returns `None`:

```python
def read_tag(self):
    try:
        target_info = self.read_target()
        ...
        return uid_hex
    except Exception as e:
        if self._debug >= 4:
            logger.debug("read_tag: gate %d error (tag removed mid-scan?): %s", ...)
        return None
```

A PN532 hardware disconnect causes `read_tag()` to return `None` — exactly the same as a missed read. `_poll()` receives `None`, calls `GateState.process_read(None, None)`, and `miss_count` increments. After `absent_threshold` consecutive `None` returns, `EVENT_REMOVED` fires normally. Polling continues throughout, with the disconnect details logged only at `debug >= 4`.

The error is therefore transparent to the state machine: a disconnected PN532 looks identical to a removed spool. The difference is visible in the log — `read_tag` errors appear alongside the miss-count increments.

---

## SpoolmanClient Circuit Breaker

SpoolmanClient prevents a slow or dead Spoolman from blocking the reactor thread on every poll. Thresholds are hardcoded in `SpoolmanClient.__init__`:
- `_CB_THRESHOLD = 3` — consecutive failures before circuit opens
- `_CB_BACKOFF = 60.0` — seconds to back off before retrying

State variables:
- `_cb_failures` — consecutive failure count; resets to 0 on any success
- `_cb_backoff_until` — `time.monotonic()` timestamp when backoff expires

Logic in `_fetch_spools()`:

```
if _cb_failures >= _CB_THRESHOLD:
    if now < _cb_backoff_until:
        → return None immediately (circuit open, no HTTP request)
    else:
        → allow one probe through (backoff elapsed)

if request succeeds:
    → reset _cb_failures = 0 (circuit closed, log "connection restored")

if request fails:
    → _cb_failures += 1
    → _cb_backoff_until = now + 60.0
    → if _cb_failures >= 3: log warning "circuit open, backing off 60s"
```

When the circuit is open, `lookup_spool_by_uid()` returns `None`. `GateState.process_read()` receives `(uid_hex, None)` — tag present, spool unknown. This fires `EVENT_UID_ONLY` → `_NFC_TAG_NO_SPOOL`. The user sees the UID logged but HH is not updated.

This is intentional: a Spoolman outage does not affect HH or printing. Gates that were already matched when Spoolman went down retain their spool assignments — the NFC cache holds the last good value and polling suspends normally. Only new assignments (new tag reads on previously empty gates) are blocked.

---

## What Gets Logged Where: Summary

| Message type | `nfc_reader.log` | `klippy.log` | Console |
|---|---|---|---|
| Per-poll / movement trace (`debug ≥ 4`, `logger.debug()` or trace console message) | ✅ | ❌ | if `console_output: True` and `console_log_level ≤ 4` |
| Integration — Spoolman / HH sync / scan state (`debug ≥ 3`, `logger.info()` or `[OK]`/`[SCAN]`/`[REWIND]`) | ✅ | ❌ | if `console_output: True` and `console_log_level ≤ 3` |
| Warnings — config issues, failure transitions (`debug ≥ 2`, `logger.warning()` or `[WARN]`) | ✅ | ✅ | if `console_output: True` and `console_log_level ≤ 2` |
| Errors — init fail, I2C error (`debug ≥ 1`, `logger.error()`) | ✅ | ✅ | ✅ always |
| PN532 init result OK (`logger.info()`) | ✅ | ❌ | ✅ via `respond_info` |
| PN532 init result failed (`logger.error()`) | ✅ | ✅ | ✅ via `respond_info` |
| Startup seed result — unconditional `logger.info()` | ✅ | ❌ | ✅ via `respond_info` |

`klippy.log` receives all `WARNING` and `ERROR` level records automatically via `_KlippyForwardHandler`. No explicit `log_both()` call is required. `INFO` and `DEBUG` records go to `nfc_reader.log` only regardless of which call site emits them.

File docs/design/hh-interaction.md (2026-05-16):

# Design: Happy Hare ↔ NFC_Manager Interaction

> Engineering reference — not end-user documentation.

---

## Interaction Model: Unidirectional Push + Poll

NFC does not have a direct Python API to Happy Hare. HH is a separate Klipper extra with its own object namespace. NFC interacts with HH in two ways:

```
NFC → HH:   GCode macro dispatch  (_NFC_SPOOL_CHANGED, _NFC_SPOOL_REMOVED, _NFC_TAG_NO_SPOOL)
HH → NFC:   none — NFC polls HH status directly via mmu.get_status()
```

There is no callback registration, no event subscription, no shared queue. NFC pushes to HH by running GCode; NFC reads from HH by calling `mmu.get_status()` at the start of each poll cycle. HH never calls into NFC.

---

## HH Status Adapter: `hh_status.py`

All reads from the HH Python object are routed through `hh_status.read()`, which returns an `HHGateStatus` data object. This isolates all raw dict access and type coercion in one place.

```python
# hh_status.py
class HHGateStatus:
    present      # bool — True if 'mmu' object exists in Klipper
    gate         # int  — gate index requested
    spool        # int  — gate_spool_id[gate], or -1
    status       # int  — gate_status[gate], or 0
    action       # str  — mmu.action, lowercased
    active_gate  # int  — currently active gate index
    filament_pos # int  — filament position in loading sequence
    gate_count   # int  — len(gate_spool_id)

    @property assigned:   spool > 0
    @property available:  status >= 1
    @property idle:       action == 'idle'
```

Usage in `nfc_manager.py`:

```python
def _read_hh_status(self, eventtime=None):
    if eventtime is None:
        eventtime = self.reactor.monotonic()
    return hh_status.read(self.printer, self._gate, eventtime)
```

If `mmu` is not registered (HH not installed), `hh_status.read()` returns `HHGateStatus(present=False, ...)` and all properties degrade to safe defaults.

---

## Print Guard: Writes Suppressed During Printing

Spoolman location writes and HH GCode dispatch are both suppressed while `print_stats.state == 'printing'` — Klipper's exact state for an actively running print. A print job may run for hours; the guard covers the entire window.

**Paused prints are explicitly excluded.** When the user pauses (`state == 'paused'`), the guard clears immediately. A filament load, unload, or spool swap during a pause goes through the full write path normally — Spoolman is updated and HH dispatch fires. This is intentional: pausing to swap filament is exactly the moment the system should respond.

| `print_stats.state` | Writes suppressed |
|---|---|
| `printing` | Yes |
| `paused` | No |
| `standby`, `complete`, `cancelled`, `error` | No |

I2C reads, Spoolman UID lookups, and GateState updates continue in all states — the system always tracks what is on each gate internally, it just does not act on changes while the print is running.

This matches HH's own behaviour: HH does not permit gate map edits during an active (non-paused) print. Issuing `MMU_GATE_MAP` or a Spoolman PATCH while `state == 'printing'` could interfere with the in-progress job.

When the print ends or is cancelled, the next poll cycle re-reads the tag and dispatches any pending change automatically. No user action is required to re-sync.

The guard applies to all event types: `EVENT_CHANGED`, `EVENT_UID_ONLY`, and `EVENT_REMOVED`. Scan-jog mode has a separate guard that prevents the jog routine from starting while `state == 'printing'`; scan-jog is also permitted during a pause.

---

## NFC → HH: GCode Macro Dispatch

`KlipperInterface.dispatch()` schedules a GCode script via `reactor.register_callback()`. This only runs when the print guard above is not active:

```
EVENT_CHANGED (Spoolman path)
  → "_NFC_SPOOL_CHANGED GATE={gate} SPOOL_ID={spool_id} UID={uid} [AUTO_CREATED=1]"

EVENT_CHANGED (metadata-direct path — Spoolman disabled, tag has filament data)
  → "_NFC_SPOOL_CHANGED GATE={gate} [NAME={name}] [MATERIAL={mat}] [COLOR={hex}] [TEMP={°C}] UID={uid}"

EVENT_UID_ONLY  → "_NFC_TAG_NO_SPOOL GATE={gate} UID={uid}"
EVENT_REMOVED   → "_NFC_SPOOL_REMOVED GATE={gate}"
```

MATERIAL, COLOR, and TEMP are each omitted when absent from tag metadata. AUTO_CREATED=1 is only present when the spool was just created by the auto-create path.

These macros are defined in `nfc_macros.cfg` and are the only user-editable integration point. If a HH version uses different command syntax, only the macro bodies need updating — the NFC Python layer is unaffected.

### `_NFC_SPOOL_CHANGED`

**Spoolman path** (`SPOOL_ID` present):
```gcode
{% if auto_created %}
MMU_SPOOLMAN REFRESH=1 QUIET=1          ; force HH to pull new spool from Spoolman
{% endif %}
MMU_GATE_MAP GATE={gate} SPOOLID={spool_id} AVAILABLE=1 SYNC=1 QUIET=1
MMU_GATE_MAP GATE={gate} APPLY=1 QUIET=1
```

**Metadata-direct path** (`SPOOL_ID` absent — Spoolman disabled, tag carries filament data):
```gcode
MMU_GATE_MAP GATE={gate} [NAME={name}] [MATERIAL={material}] [COLOR={color}] [TEMP={temp}] AVAILABLE=1 QUIET=1
MMU_GATE_MAP GATE={gate} APPLY=1 QUIET=1
```

`SYNC=1` tells HH to synchronize the assignment to Spoolman. `AVAILABLE=1` marks the gate as having filament loaded. `APPLY=1` pushes the updated map into the active print state. `MMU_SPOOLMAN REFRESH=1` is called before `MMU_GATE_MAP` when `AUTO_CREATED=1` so HH's Spoolman cache includes the newly created spool before the assignment is made. NFC does not PATCH Spoolman `location` directly; Happy Hare owns that synchronization through `MMU_SPOOLMAN SYNC=1 QUIET=1`.

### `_NFC_SPOOL_REMOVED`

```gcode
{% set mmu_action = printer.mmu.action | default("") | lower %}
{% if "load" in mmu_action or "unload" in mmu_action or "homing" in mmu_action %}
    { action_respond_info("... ignoring removal.") }
{% else %}
    MMU_GATE_MAP GATE={gate} SPOOLID=-1 AVAILABLE=0 SYNC=1 QUIET=1
    MMU_GATE_MAP GATE={gate} APPLY=1 QUIET=1
{% endif %}
```

**MMU action guard:** before clearing the gate, the macro reads `printer.mmu.action`. If the MMU is loading, unloading, or homing, the removal event is silently ignored. This prevents a tag momentarily leaving read range during filament movement from triggering a spurious gate clear. The removal will be retried on the next poll cycle if the tag is still absent.

The macro calls `MMU_SPOOLMAN SYNC=1 QUIET=1` after the gate map update so Happy Hare synchronizes the cleared assignment to Spoolman.

### `_NFC_TAG_NO_SPOOL`

```gcode
{ action_respond_info("NFC gate %d: tag UID %s is not registered in Spoolman.\n..." % ...) }
```

Logs the UID to the console and prompts the user to register it. Does not call `MMU_GATE_MAP`. No HH state changes.

---

## HH → NFC: Status Polling

NFC reads HH state by calling `hh_status.read()` which calls `mmu.get_status()` on the HH Python object. This is a synchronous in-process call — no GCode queue, no I2C.

Used in two places:

**`_hh_gate_matches_current_spool()`** — returns True when `hh.spool == nfc_spool` (exact match, not just `> 0`). Called at the top of every `_poll()` to decide whether to suspend scanning. Also called from `_poll_timer_event` on every tick when `gate_status == 0`.

**`_check_hh_cleared()`** — compares NFC's cached spool against HH's current value. Detects:
- HH cleared the gate: `not hh.assigned`
- HH has a different spool: `hh.spool != nfc_spool`

Only runs when `_hh_confirmed_spool == _state.current_spool` — prevents a loop where NFC dispatches a spool, HH hasn't processed it yet, the check sees the old HH state, and clears the cache before HH can acknowledge.

---

## Startup Seeding

On `klippy:connect`, `_delayed_init` runs 2 seconds later and calls `_seed_cache_from_hh()` — directly in Python, not via a macro.

```python
# Simplified from _seed_cache_from_hh()
hh = hh_status.read(self.printer, self._gate, eventtime)

if hh.assigned:
    self._hh_seed_spool_id  = hh.spool
    self._hh_seed_available = hh.available

    if hh.available and self._spoolman is not None:
        uid = self._spoolman.get_uid_for_spool(hh.spool)  # Spoolman reverse-lookup
        if uid:
            self._state.current_uid   = uid        # cache fully populated
            self._state.current_spool = hh.spool   # polling suspends immediately
            self._hh_confirmed_spool  = hh.spool
```

When the Spoolman reverse-lookup succeeds: the gate goes directly to the "suspended" state on the first `_poll()` cycle. `NFC_STATUS` shows the correct UID immediately, before any physical scan.

When the Spoolman lookup fails (no UID in Spoolman, or Spoolman not configured): only `_hh_seed_spool_id` is set. Polling proceeds normally. On the first physical scan that resolves to the seeded spool, the dispatch is suppressed (HH already knows).

**`NFC_HH_SYNC_CACHE` macro** is a user-callable re-sync path — it calls `NFC GATE=n HH_SYNC=1 SPOOL_ID=<n>` for each lane, which sets `_hh_seed_spool_id` only (no Spoolman reverse-lookup, no state pre-population). Its comment says: "startup seeding happens automatically in Python (`_delayed_init`). This macro exists for user-triggered re-sync and for cases where the Python seed failed."

---

## Suspend/Resume Cycle: Full Trace

```
1. Gate 0 is empty. Polling runs every 10 s. read_tag() fires each cycle.
   GateState: uid=None spool=None misses=0

2. User loads a spool. On next poll, NFC reads the tag.
   read_tag() → uid_hex = "A3F200CC"

3. SpoolmanClient.lookup_spool_by_uid("A3F200CC") → spool_id = 42
   (HTTP request if cache cold, cache hit if warm)

4. GateState.process_read("A3F200CC", 42) → EVENT_CHANGED
   GateState: uid="A3F200CC" spool=42 misses=0

5. Not suppressed (no matching seed, no CLEAR_CACHE pending).
   NFC does not PATCH Spoolman location directly; HH will synchronize it.
   KlipperInterface.dispatch(EVENT_CHANGED, 0, "A3F200CC", 42)
   _hh_confirmed_spool = 42   (set optimistically when callback is SCHEDULED)

6. reactor.register_callback fires → gcode.run_script:
       _NFC_SPOOL_CHANGED GATE=0 SPOOL_ID=42 UID=A3F200CC
   Macro executes:
       MMU_GATE_MAP GATE=0 SPOOLID=42 AVAILABLE=1 SYNC=1 QUIET=1
       MMU_GATE_MAP GATE=0 APPLY=1 QUIET=1
   HH now has gate_spool_id[0] = 42.

7. Next poll cycle (10 s later):
   hh = hh_status.read(...)  → hh.spool = 42
   _hh_gate_matches_current_spool() → True (hh.spool == nfc_spool == 42)
   current_spool = 42, not None → both suspend conditions met
   _hh_load_paused = True
   miss_count zeroed, return early. PN532 not pulsed.

   Note: _hh_confirmed_spool is set in step 5 when the callback is *scheduled*,
   before HH actually processes the macro. If a poll fires in the narrow window
   between scheduling and HH execution, hh.spool may still show -1. In that window
   _hh_gate_matches_current_spool() returns False and the poll reads the tag again —
   process_read() sees same uid+spool → None (quiet). No harm done.

8. Timer keeps firing every 10 s. Each cycle:
   _hh_gate_matches_current_spool() → True, current_spool set
   → miss_count zeroed, return. No I2C traffic.

9. User ejects spool. HH clears gate:
   gate_spool_id[0] = -1

10. Next poll cycle: _hh_gate_matches_current_spool() → False (hh.spool != 42).
    _hh_load_paused was True → resume path fires:
      _hh_load_paused    = False
      current_uid        = None
      current_spool      = None
      miss_count         = 0
      _hh_confirmed_spool = None

    _check_hh_cleared() runs — current_spool is now None, returns early.
    read_tag() fires. Gate is empty → uid_hex = None.
    GateState.process_read(None, None) → miss_count = 1 → None (still counting)

11. After absent_threshold polls (3 × 10 s = ~30 s) with no tag:
    GateState.process_read(None, None) → EVENT_REMOVED
    _NFC_SPOOL_REMOVED GATE=0 dispatched.
    Macro checks printer.mmu.action — if idle, clears HH gate map.
```

---

## Happy Hare Compatibility Contract

### `mmu.get_status()` — Required Keys

Called via `hh_status.read()` which accesses these keys with `.get(key, default)`:

| Key | Type | Used in | Purpose |
|---|---|---|---|
| `gate_spool_id` | `list[int]` | `_seed_cache_from_hh`, `_check_hh_cleared`, `_hh_gate_matches_current_spool`, `_hh_filament_label` | Spool ID per gate; `-1` = empty/unknown |
| `gate_status` | `list[int]` | `_seed_cache_from_hh`, `_hh_filament_label`, scan-jog edge detection | Availability flag per gate; `0` = unavailable, `≥1` = available |
| `action` | `str` | all `_read_hh_status()` callers | MMU action string, lowercased; `'idle'` checked in `HHGateStatus.idle` |
| `gate` | `int` | `_hh_filament_label` | Index of currently active gate |
| `filament_pos` | `int` | `_hh_filament_label` | Current filament position; `0` = at/before gate |

Missing keys degrade to safe defaults (`HHGateStatus` fields initialize to `-1` / `0` / `''`).

### `printer.mmu.*` — Jinja2 Template Variables

Accessed in `nfc_macros.cfg` via the Klipper template engine:

| Variable | Type | Used in | Purpose |
|---|---|---|---|
| `printer.mmu.action` | `str` | `_NFC_SPOOL_REMOVED` | MMU action string. Removal suppressed when containing `"load"`, `"unload"`, or `"homing"`. |
| `printer.mmu.num_gates` | `int` | `NFC_HH_SYNC_CACHE` | Total configured MMU gates; used to iterate the gate map. |
| `printer.mmu.gate_spool_id` | `list[int]` | `NFC_HH_SYNC_CACHE` | Same as `gate_spool_id` above. |
| `printer.mmu.gate_status` | `list[int]` | `NFC_HH_SYNC_CACHE` | Same as `gate_status` above. |

### GCode Commands Issued

All GCode is dispatched from `nfc_macros.cfg`. The NFC Python layer never calls HH commands directly.

| Command | Parameters | Issued from | Purpose |
|---|---|---|---|
| `MMU_SPOOLMAN` | `REFRESH=1 QUIET=1` | `_NFC_SPOOL_CHANGED` (auto-create only) | Force HH to pull newly created spool from Spoolman before assignment |
| `MMU_GATE_MAP` | `GATE=N SPOOLID=N AVAILABLE=1 SYNC=1 QUIET=1` | `_NFC_SPOOL_CHANGED` (Spoolman path) | Assign spool to gate and mark available |
| `MMU_GATE_MAP` | `GATE=N [NAME=X] [MATERIAL=X] [COLOR=X] [TEMP=N] AVAILABLE=1 QUIET=1` | `_NFC_SPOOL_CHANGED` (metadata path) | Set gate filament metadata when Spoolman is disabled |
| `MMU_GATE_MAP` | `GATE=N APPLY=1 QUIET=1` | `_NFC_SPOOL_CHANGED`, `_NFC_SPOOL_REMOVED` | Push updated map into active print state |
| `MMU_GATE_MAP` | `GATE=N SPOOLID=-1 AVAILABLE=0 SYNC=1 QUIET=1` | `_NFC_SPOOL_REMOVED` | Clear gate assignment |
| `MMU_SELECT` | `GATE=N` | scan-jog first jog only | Set active gate for `MMU_TEST_MOVE` |
| `MMU_TEST_MOVE` | `MOVE=mm QUIET=1` | scan-jog each jog step and rewind | Drive gear stepper |

`SYNC=1` tells HH to synchronise the assignment to Spoolman. `QUIET=1` suppresses HH console output.

### Version Requirements

These parameters (`SYNC`, `QUIET`, `APPLY`) were introduced in **Happy Hare v2.x**. The NFC macros are not compatible with Happy Hare v1.x. No minimum patch version within v2 has been formally validated.

---

## Design Invariants

- NFC does not read or write HH's internal Python objects directly — only via `hh_status.read()` (read) and GCode macros (write).
- NFC does not listen for HH events (`printer.register_event_handler('mmu:...')` is not used).
- NFC does not call `MMU_GATE_MAP` directly — only the user-editable macros in `nfc_macros.cfg` do.
- NFC does not disable itself when HH is absent. With no `mmu` object: scanning never suspends, `_check_hh_cleared()` is a no-op, and GCode dispatches still fire — but HH macros will fail with "Unknown command" if HH isn't installed.

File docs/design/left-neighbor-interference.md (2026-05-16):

# Design: Left-Neighbor Tag Interference During Scan-Jog

> Engineering reference. Not end-user documentation.
> Status: **Implemented** — `scan_jog.py` mitigation, `nfc_manager.py`
> lane lookup support, and scan-jog tests.

## Problem

Some tagged spools expose NFC/RFID tags on both sides of the spool. In an EMU
layout where each PN532 reader is mounted on the left side of its own spool, the
reader for gate `N` can occasionally see the tag on gate `N - 1` instead of the
spool currently being scan-jogged.

This is most likely during scan-jog:

- gate `N` is rotating to find its own tag
- gate `N - 1` is already loaded and parked
- one side tag on gate `N - 1` is sitting in gate `N` reader's field

The current NFC state machine assumes the UID returned by a gate reader belongs
to that gate. That assumption is still correct for normal operation, but it can
misassign a spool during this physical edge case.

## Scope

Recommended scope is intentionally narrow:

- only inspect the immediate left neighbor, `gate - 1`
- do nothing for gate `0`
- only apply mitigation while scan-jog is active
- only apply mitigation while Happy Hare is idle and lanes passed the existing
  parked-or-empty preflight
- do not add a configuration option
- always restore the left neighbor if it was moved
- do not add global cross-gate UID matching

This keeps the behavior matched to the physical mounting geometry instead of
turning the NFC manager into a global spool reconciliation system.

## Existing Safety Boundaries

The current implementation already provides useful protection:

- only one scan-jog may run at a time via `NFCGate._active_scan_gate`
- scan-jog is blocked unless Happy Hare reports all lanes parked or empty
- each gate owns its own reader
- scan-jog suppresses dispatch until after the rewind path
- incomplete structured reads can be retried nearby

The missing piece is identity disambiguation after a UID is read but before the
scan is accepted as successful.

## Insertion Point

The implementation lives in:

`klippy/extras/nfc_gates/scan_jog.py`

The best insertion point is inside `step_event()`, immediately after:

```python
tag_found = gate._poll()
```

and before the existing `if tag_found:` success path.

At this point:

- the PN532 read has happened
- `tag_handler.resolve_spool()` has already resolved UID to spool where possible
- `GateState.process_read()` has updated `gate._state`
- scan-jog dispatch is still deferred in `gate._scan_found_event`
- no Happy Hare assignment has been sent yet

That makes it possible to reject the read, clear the deferred event, move the
left neighbor out of the RF field, and continue scanning gate `N`.

Implemented call shape:

```python
tag_found = gate._poll()

if tag_found and handle_left_neighbor_interference(gate, now):
    return gate.reactor.monotonic() + gate._scan_poll_interval
```

## Detection Strategy

### Spoolman-enabled path

If Spoolman is enabled, the first identity test should still be UID-to-UID, not
UID-to-spool. The raw UID is the direct physical identity returned by the PN532.
If gate `N` reads the same UID already known for gate `N - 1`, the tag belongs
to the left neighbor and there is no reason to resolve the read UID to a
Spoolman spool before acting.

Implemented order:

1. Confirm a UID was read.
2. Find the known UID for gate `N - 1` from the left NFC gate object.
3. If the left gate has a known UID and it matches the read UID, treat the read
   as interference immediately.
4. Discard the read, jog gate `N - 1` out of the reader field, and continue
   scan-jog for gate `N`.
5. If the left UID is unavailable or does not match, fall out to the default
   scan-jog behavior.

This avoids unnecessary Spoolman resolution for the common strong-match case.
The UID comparison is both safer and more efficient: it answers "did this
reader see the left physical tag?" directly.

Helper logic:

```python
def read_uid_from_scan_event(gate):
    event = getattr(gate, '_scan_found_event', None)
    if event is not None and len(event) >= 3:
        return event[2]
    return gate._state.current_uid
```

Then:

```python
left_gate = gate._gate - 1
if left_gate < 0:
    return False

read_uid = read_uid_from_scan_event(gate)
if read_uid is None:
    return False

left_uid = known_uid_for_gate(gate, left_gate)
if left_uid is not None and left_uid == read_uid:
    return True
```

The `known_uid_for_gate()` helper is cheap and conservative. Preferred source:

1. The left `NFCGate` instance cache, if it has `current_uid`.

Happy Hare may be used as a safety check that the left gate is still physically
loaded or available, but it should not be used to resolve the UID that gate `N`
just read. Likewise, the first implementation should not fall back from
`read_uid` to `spool_id` comparison. If the left NFC gate cache has no UID,
there is no positive interference proof.

If no left UID can be established, or if the known left UID does not match the
read UID, the mitigation should return `False` and let normal scan-jog continue.
The resolved `spool_id` is useful for the normal assignment flow, but it is not
the primary decision point for left-neighbor interference.

### Spoolman-disabled path

When Spoolman is disabled, the same UID-first rule still applies. Do not invent
a Happy Hare metadata convention just to smuggle the UID through display names.
The NFC layer already owns per-gate state, and `NFC_STATUS` already shows each
gate's cached UID from the `NFCGate` object.

Recommended order:

1. Confirm a UID was read by gate `N`.
2. Resolve the left NFC gate object for `N - 1`.
3. Read `left_gate._state.current_uid`.
4. If the left NFC gate has a cached UID and it matches the read UID, treat the
   read as interference immediately.
5. If the left NFC gate has no cached UID, or the UID does not match, return
   `False` and let normal scan-jog continue.

This keeps the no-Spoolman path a corner case with the same core rule:

```python
left_nfc = nfc_gate_for_gate_number(gate._gate - 1)
if left_nfc is None:
    return False

left_uid = left_nfc._state.current_uid
return left_uid is not None and left_uid == read_uid
```

Happy Hare can still be used as a sanity check that the left lane is physically
loaded or available, but HH does not need to carry the UID. The UID comparison
should come from the NFC gate cache, not from gate names or display metadata.

## Mitigation Strategy

If the current scan reads the left neighbor:

1. Log the decision, including current gate, left gate, UID, and spool ID when
   available.
2. Select the left gate.
3. Jog the left gate in the positive `MMU_TEST_MOVE` direction by a fixed
   distance. This is the "push filament out" direction for the parked left
   neighbor.
4. Wait for the move to complete.
5. Re-select the current scan gate.
6. Clear the false scan result.
7. Continue the scan-jog loop.

Up to three clearance moves may be attempted per scan. After each move, the
false scan result is cleared and the current lane reads again before any normal
current-lane jog is queued. If the same scan still reads the left neighbor
after the third clearance move, treat that as a larger mechanical/RF fault.
Log and console an `[ERROR]`, abort scan-jog for the current gate, restore the
left neighbor by the accumulated clearance distance, and rewind the current
gate through the normal scan exit path.

Fixed distance:

```python
LEFT_NEIGHBOR_CLEARANCE_MM = 75.0
```

No config option is recommended. A fixed value keeps the feature simple and
avoids adding a tuning knob for a rare hardware geometry problem.

Clearance GCode sequence:

```gcode
MMU_SELECT GATE=<left>
MMU_TEST_MOVE MOVE=75.00 QUIET=1
M400
MMU_SELECT GATE=<current>
```

After shifting the neighbor, clear the false read:

```python
gate._scan_found_event = None
gate._state.current_uid = None
gate._state.current_spool = None
gate._state.miss_count = 0
```

If a structured tag object is present, clear it as well:

```python
gate._state.current_tag = None
```

## Restore Strategy

If the left neighbor was moved, it must be restored from every scan exit path:

- successful scan
- no tag found
- max distance reached
- print-start abort
- scan poll exception path that exits scan-jog

State on `NFCGate`:

```python
gate._scan_left_neighbor_gate = -1
gate._scan_left_neighbor_shift_mm = 0.0
gate._scan_left_neighbor_shifted = False
gate._scan_left_neighbor_uid = None
gate._scan_left_neighbor_attempts = 0
```

Initialize these in `scan_jog.start()`.

Restore helper:

```python
def restore_left_neighbor(gate):
    if not getattr(gate, '_scan_left_neighbor_shifted', False):
        return
    left = gate._scan_left_neighbor_gate
    mm = gate._scan_left_neighbor_shift_mm
    gate._scan_left_neighbor_shifted = False
    gate._scan_left_neighbor_gate = -1
    gate._scan_left_neighbor_shift_mm = 0.0
    gate._scan_left_neighbor_uid = None

    gcode = gate.printer.lookup_object('gcode')
    gcode.run_script(
        "MMU_SELECT GATE=%d\n"
        "MMU_TEST_MOVE MOVE=%.2f QUIET=1\n"
        "M400\n"
        "MMU_SELECT GATE=%d" % (left, -mm, gate._gate))
```

Call this from both `finish()` and `rewind_and_exit()`. The restore should run
after the current gate's rewind is queued, and before the scan state is fully
cleared. The final `MMU_SELECT GATE=<current>` leaves Happy Hare selected on the
gate whose scan just completed.

## State Reset and Scan Continuation

Handling interference should not count as a successful scan. It should behave
like "that UID was not ours; try again after moving the neighbor".

Recommended behavior after the left gate jog:

- keep `gate._scan_mode = True`
- keep `NFCGate._active_scan_gate` held by the current gate
- keep `gate._scan_mm_total` unchanged
- clear current NFC state and deferred event
- set `gate._scan_next_chunk_time` to a short future time so the field can
  settle before polling again

Example:

```python
gate._scan_next_chunk_time = (
    gate.reactor.monotonic() + DECODE_RETRY_SETTLE_DELAY)
```

Using the existing decode retry settle constant is acceptable. A separate
constant can be introduced if hardware testing shows the neighbor shift needs a
different dwell.

## Implementation Notes

This section describes the implemented first pass.

### Identity Rule

Use exactly one positive interference rule:

```text
gate N read UID X
left NFC gate cache has current_uid Y
X == Y  -> left-neighbor interference
X != Y  -> normal scan-jog behavior
Y empty -> normal scan-jog behavior
```

Do not resolve the read UID to a Spoolman spool ID for interference detection.
Do not compare the read spool ID to Happy Hare's left-gate spool ID. Do not
inspect Happy Hare display names or metadata for UID information.

### Data Sources

The current read UID comes from the current gate's scan state, in this order:

1. `gate._scan_found_event[2]`, if a deferred scan event exists
2. `gate._state.current_uid`

The left UID comes from the left NFC gate object only:

```python
left_nfc = nfc_gate_for_gate_number(gate._gate - 1)
left_uid = left_nfc._state.current_uid if left_nfc is not None else None
```

Happy Hare may be consulted only to reject stale left-cache data:

```python
left_hh = hh_status.read(gate.printer, gate._gate - 1)
if left_hh.present and not left_hh.available:
    return None
```

If Happy Hare is unavailable, the implementation may still use the left NFC
cache because scan-jog already passed its preflight before starting. The
important part is that HH is not used to translate the current read into an
identity.

### Helper Contracts

Add a lookup helper near the existing `_lane_instances` registry in
`nfc_manager.py`:

```python
def nfc_gate_for_gate_number(gate_number):
    for candidate in _lane_instances:
        if candidate._gate == gate_number:
            return candidate
    return None
```

Expose it to `scan_jog.py` through an `NFCGate` wrapper to avoid importing
`nfc_manager.py` from `scan_jog.py`:

```python
def _nfc_gate_for_gate_number(self, gate_number):
    return nfc_gate_for_gate_number(gate_number)
```

Then `scan_jog.py` can call:

```python
left_nfc = gate._nfc_gate_for_gate_number(gate._gate - 1)
```

### Scan Loop Placement

In `scan_jog.step_event()`, call the interference handler immediately after
`gate._poll()` and before decode retry or finish handling:

```python
tag_found = gate._poll()

if tag_found and handle_left_neighbor_interference(gate, now):
    return gate.reactor.monotonic() + gate._scan_poll_interval
```

This placement matters. `_poll()` has already captured the UID and deferred the
event, but scan-jog has not accepted the read, started decode retry, dispatched
to Happy Hare, or finished.

### Interference Handler

The handler should:

1. Read the current scan UID.
2. Return `False` for gate `0`.
3. Return `False` if the current UID is empty.
4. Read the left NFC gate object and its `current_uid`.
5. Return `False` if the left UID is empty or does not match.
6. If the left neighbor was already shifted during this scan and the same left
   gate/UID is still being read, log a fault, abort scan-jog, and return `True`.
7. Log the interference decision.
8. Move the left gate out of range. If the shift command fails, log the
   failure, clear no scan state, return `False`, and let normal scan-jog
   behavior continue.
9. Clear the current gate's false read state.
10. Keep scan-jog active and return `True`.

The handler should not inspect or compare spool IDs.

### Left-Gate Movement

Use a single fixed displacement:

```python
LEFT_NEIGHBOR_CLEARANCE_MM = 75.0
```

The shift GCode should explicitly select the left gate, move it in the positive
`MMU_TEST_MOVE` direction to push filament out, wait, then select the current
gate:

```gcode
MMU_SELECT GATE=<left>
MMU_TEST_MOVE MOVE=75.00 QUIET=1
M400
MMU_SELECT GATE=<current>
```

Set restore state only after the shift command is successfully queued:

```python
gate._scan_left_neighbor_gate = left
gate._scan_left_neighbor_shift_mm = 75.0
gate._scan_left_neighbor_shifted = True
gate._scan_left_neighbor_uid = uid
```

If the shift command raises, log a warning, clear no state, and return `False`
so normal scan-jog behavior continues.

Retry clearance moves conservatively. If `gate._scan_left_neighbor_shifted` is
already `True` for the same left gate and UID, the implementation may call
`MMU_TEST_MOVE MOVE=75.00` again until three total clearance moves have been
queued. Each retry clears the false scan result and reads again before normal
current-lane scan-jog movement resumes.

If the same UID is still visible after the third clearance move and follow-up
read, report an error and exit scan-jog:

```text
[ERROR] NFC[<current>]: left lane gate <left> is interfering with the current lane read after 3 clearance moves (<mm>mm); check reader position, tag placement, or lane spacing
```

That exit should use the normal rewind/restore path so the neighbor is returned
with `MMU_TEST_MOVE MOVE=-<total clearance>` and the current gate is rewound.

### False Read Cleanup

After a confirmed left-neighbor UID match and successful left-gate shift, clear:

```python
gate._scan_found_event = None
gate._state.current_uid = None
gate._state.current_spool = None
gate._state.current_tag = None
gate._state.miss_count = 0
```

Also clear decode-retry state if it had been initialized from the false UID:

```python
gate._scan_decode_retry_attempts = 0
gate._scan_decode_retry_uid = None
gate._scan_decode_retry_offset = 0.0
```

Do not change `gate._scan_mm_total`; the current gate has not moved.

### Restore Ordering

Call `restore_left_neighbor(gate)` from both scan exit paths:

- `finish(gate)`
- `rewind_and_exit(gate)`

The restore should run after the current gate's rewind is queued and before the
scan state is fully discarded. This preserves the current gate's normal rewind
behavior and still guarantees the neighbor is put back.

Restore GCode:

```gcode
MMU_SELECT GATE=<left>
MMU_TEST_MOVE MOVE=-75.00 QUIET=1
M400
MMU_SELECT GATE=<current>
```

Clear restore state before running the restore GCode so a restore failure cannot
cause repeated negative moves on later cleanup attempts. Log failures.

## Module Changes

### `scan_jog.py`

Owns:

- interference detection wrapper
- left-neighbor jog GCode
- restore-on-exit state
- clearing false scan results

Recommended additions:

- `LEFT_NEIGHBOR_CLEARANCE_MM`
- `handle_left_neighbor_interference(gate, now)`
- `is_left_neighbor_interference(gate, uid, spool)`
- `shift_left_neighbor(gate)`
- `restore_left_neighbor(gate)`
- `clear_false_scan_result(gate)`

### `nfc_manager.py`

Keep changes minimal.

Add scan state fields in `NFCGate.__init__` so tests and status are explicit:

```python
self._scan_left_neighbor_gate = -1
self._scan_left_neighbor_shift_mm = 0.0
self._scan_left_neighbor_shifted = False
self._scan_left_neighbor_uid = None
```

Expose or reuse a small lookup helper for the existing NFC gate registry:

```python
def nfc_gate_for_gate_number(gate_number):
    for candidate in _lane_instances:
        if candidate._gate == gate_number:
            return candidate
    return None
```

This helper lets scan-jog read the left gate's cached `current_uid` directly
from the NFC gate object. That is the right source for UID identity; Happy Hare
does not need a UID field for this mitigation.

No Happy Hare movement commands should be added here. Movement remains in
`scan_jog.py`.

### `hh_status.py`

No display-name or metadata changes are required for this design.

`hh_status.py` may still be used to verify the left lane is physically loaded or
available before trusting a cached UID, but it should not be extended to carry
UIDs through Happy Hare gate metadata.

### `klipper_interface.py`

No changes are required.

Do not append UID suffixes to metadata names for this mitigation. Display names
should remain display names; UID identity stays in the NFC gate cache.

## Pseudocode

```python
def handle_left_neighbor_interference(gate, now):
    if not gate._scan_mode:
        return False
    if gate._gate <= 0:
        return False

    event = getattr(gate, '_scan_found_event', None)
    uid = None
    spool = gate._state.current_spool
    if event is not None and len(event) >= 4:
        uid = event[2]
        spool = event[3]
    if uid is None:
        uid = gate._state.current_uid
    if uid is None:
        return False

    if not is_left_neighbor_interference(gate, uid, spool):
        return False

    left_gate = gate._gate - 1
    if left_neighbor_already_shifted(gate, left_gate, uid) and attempts >= 3:
        msg = (
            "[ERROR] NFC[%d]: left lane gate %d is interfering with the "
            "current lane read after %d clearance moves"
            % (gate._gate, left_gate, attempts))
        logger.error("%s", msg)
        gate._console(msg)
        clear_false_scan_result(gate)
        gate._rewind_and_exit_scan()
        return True

    logger.warning(
        "nfc_gate: [%s] gate %d scan mode - uid=%s spool=%s belongs "
        "to left neighbor gate %d; moving neighbor out of reader field",
        gate._name, gate._gate, uid, spool, left_gate)

    if not shift_left_neighbor(gate):
        return False
    clear_false_scan_result(gate)
    gate._scan_next_chunk_time = (
        gate.reactor.monotonic() + DECODE_RETRY_SETTLE_DELAY)
    return True

def left_neighbor_already_shifted(gate, left_gate, uid):
    return (
        gate._scan_left_neighbor_shifted
        and gate._scan_left_neighbor_gate == left_gate
        and gate._scan_left_neighbor_uid == uid)

def is_left_neighbor_interference(gate, uid, spool):
    if gate._gate <= 0:
        return False
    if uid is None:
        return False

    left_gate = gate._gate - 1
    left_uid = known_uid_for_gate(gate, left_gate)
    if left_uid is None:
        return False

    return left_uid == uid

def known_uid_for_gate(gate, target_gate):
    left_nfc = gate._nfc_gate_for_gate_number(target_gate)
    if left_nfc is None or not left_nfc._state.current_uid:
        return None

    # Optional stale-cache guard. HH is not used to resolve identity; it can
    # only veto a cached left UID when it clearly says the left gate is empty.
    left = hh_status.read(gate.printer, target_gate)
    if left.present and not left.available:
        return None

    return left_nfc._state.current_uid
```

## Tests

Add tests to:

`tests/test_scan_jog_mode.py`

Recommended cases:

- gate `0` never checks a left neighbor
- Spoolman-enabled read matching the known left UID shifts left and does not finish
  scan
- Spoolman-enabled read not matching the known left UID finishes normally
- Spoolman-enabled read with no known left UID falls through to normal scan-jog
  behavior
- left gate assigned but not available does not trigger mitigation
- after interference, false `_scan_found_event` and `GateState` values are
  cleared
- `finish()` restores the left gate if shifted
- `rewind_and_exit()` restores the left gate if shifted
- repeated left-neighbor hits after the first clearance do not issue another
  `MOVE=75.00`; they warn, abort scan-jog, restore the neighbor, and rewind the
  current gate
- Spoolman-disabled read matching the left NFC gate object's cached UID shifts
  left and does not finish scan
- Spoolman-disabled read with no cached left UID falls through to normal
  scan-jog behavior

The tests should assert emitted GCode order, especially:

```text
MMU_SELECT GATE=<left>
MMU_TEST_MOVE MOVE=75.00 QUIET=1
M400
MMU_SELECT GATE=<current>
```

and restore:

```text
MMU_SELECT GATE=<left>
MMU_TEST_MOVE MOVE=-75.00 QUIET=1
M400
MMU_SELECT GATE=<current>
```

## Risks and Notes

- The no-Spoolman path depends on the left NFC gate object having a current UID
  in its cache. If it does not, the mitigation should degrade gracefully by
  returning `False` and letting normal scan-jog continue.
- Moving the left neighbor assumes all lanes are parked or empty. The existing
  scan-jog preflight is therefore part of this feature's safety case.
- If the reader still sees the same left-neighbor UID after a 75mm clearance
  move, the problem is likely mechanical placement, reader field overlap, tag
  placement, or lane spacing. The implementation should surface that condition
  clearly and stop the scan instead of pushing the neighbor farther out.
- The mitigation should be conservative about what counts as interference.
  False positives move a neighboring parked spool unnecessarily. False
  negatives preserve current behavior.
- The feature should log clearly but avoid console spam. A single warning per
  interference event is enough.

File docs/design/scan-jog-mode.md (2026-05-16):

# Design: Scan-and-Jog Mode (Spool Pre-load NFC Identification)

> Engineering reference — not end-user documentation.
> Status: **Implemented** — `scan_jog.py` module, integrated into `nfc_manager.py`
> Source: `klippy/extras/nfc_gates/scan_jog.py`, `klippy/extras/nfc_gates/nfc_manager.py`

---

## Problem Statement

When a spool is manually loaded into a lane, Happy Hare parks the filament at the gate entrance (gate_status → 1, action → Idle). At that point the NFC tag is on the spool hub — potentially centimeters away from the PN532 antenna. The normal polling loop may not read the tag at all if the hub face isn't already aligned over the reader. The user needs a mode where, after filament is parked at the gate, the system automatically spins the spool in small increments to find the tag, identifies the spool, and then winds back to the parked position.

---

## Constraints

- Must not run during an active print.
- Must not run while HH is executing any MMU operation (Loading, Unloading, Homing, etc.).
- Must not require a GCode macro to drive the loop — the control logic must stay in Python.
- Must rewind to the original parked position.
- Rewind must fire even if the search is aborted (max distance reached, print starts mid-scan).
- Must not use `UPDATE_DELAYED_GCODE` — timer lifecycle is owned entirely by the Klipper reactor.

---

## Why Not a GCode Macro Loop

Driving the jog loop from GCode would require a `[delayed_gcode]` that reschedules itself, a cancel mechanism (no clean cancel exists), and scope crossing on every iteration. The Python-only approach eliminates all three problems. Reactor timers are first-class objects: they start, reschedule, and cancel entirely within `_scan_step_event` return values. The jog command (`MMU_TEST_MOVE`) is still issued via `gcode.run_script()`, which is safe from the reactor thread — the same pattern used by `KlipperInterface._run_gcode()`.

---

## Code Structure

All scan-jog logic lives in `klippy/extras/nfc_gates/scan_jog.py` as module-level functions. `NFCGate` in `nfc_manager.py` delegates to them via thin wrapper methods:

```python
# NFCGate wrappers in nfc_manager.py
def _start_scan_mode(self):   return scan_jog.start(self)
def _scan_step_event(self, t): return scan_jog.step_event(self, t)
def _finish_scan(self):        return scan_jog.finish(self)
def _rewind_and_exit_scan(self): return scan_jog.rewind_and_exit(self)
def _run_jog(self, mm):        return scan_jog.run_jog(self, mm)
def _run_rewind(self):         return scan_jog.run_rewind(self)
```

`gate` is passed as the first argument to every `scan_jog` function so it can read and write `gate._scan_mode`, `gate._scan_mm_total`, etc. directly.

---

## Trigger Detection

Trigger detection is folded into `_poll_timer_event`. The gate-status edge-detection path runs every tick when `scan_enabled` is True:

```
_poll_timer_event (every poll_interval)
  ├── read HH gate_status (Python dict — no I2C)
  │
  ├── curr == 0  → skip I2C entirely; also handles _hh_load_paused resume/suspend
  │
  ├── 0→1 edge  → set _scan_pending = True; reset _scan_idle_ready_time
  │
  ├── _scan_pending == True AND curr == 1 AND hh.idle AND not printing
  │     first fire:  _scan_idle_ready_time = now + 2.0  → return that time
  │     settled:     _scan_pending = False
  │                  if NFCGate._active_scan_gate is not None:
  │                      re-arm _scan_pending, retry in 3.0 s
  │                  else:
  │                      _start_scan_mode() → park poll timer, return NEVER
  │
  └── _scan_pending == True but conditions not met → return now + 1.0
```

**Key details:**
- `_prev_gate_status` initializes to `-1` on startup. The `-1 → 1` transition at cold start is ignored; only `0 → 1` triggers scan mode. This prevents a false trigger when HH already has `gate_status = 1` from a previous session.
- A 2-second idle-settle delay (`_scan_idle_ready_time`) is inserted after HH reports idle. This prevents premature scan entry while HH is still completing its park move.
- If another gate holds the scan lock, `_scan_pending` is re-armed and a 3-second retry is scheduled rather than silently dropping the trigger or spamming logs.

**Manual trigger:** `NFC GATE=N JOG_SCAN=1` calls `scan_jog.manual_jog_scan(gate, gcmd)` directly. It runs the same precondition checks (not printing, HH idle, no other gate scanning, reader healthy) and calls `start(gate)`. No edge detection is involved. Happy Hare prep is always required, but `_NFC_GATE_CLEAR_CACHE GATE=N` and `MMU_SPOOLMAN SYNC=1` are deferred to the scan timer so a Happy Hare post-preload hook can return before NFC calls back into HH.

---

## Gate Context and Scan Lock

If two lanes entered scan mode concurrently, their `MMU_SELECT GATE=N` calls would interleave and `MMU_TEST_MOVE` would move the wrong lane's filament. Because all `nfc_gate` instances run on the same reactor thread, a **class-level lock** is sufficient:

```python
# Class variable — shared across all NFCGate instances
NFCGate._active_scan_gate = None   # gate number that currently holds the lock, or None
```

Rules:
- **Entry**: `scan_jog.start()` sets `NFCGate._active_scan_gate = gate._gate`.
- **Hold**: while scan is running, `_active_scan_gate` is non-None. Other gates re-arm `_scan_pending` and retry in 3 seconds.
- **Release**: both `finish()` and `rewind_and_exit()` set `NFCGate._active_scan_gate = None`.
- `_handle_disconnect` also clears the lock if this gate owns it.

Normal polling (I2C reads, no MMU moves) is not gated by this lock.

---

## State Machine

```
              klippy:
              connect ──► POLLING ──(0→1, HH idle, not printing)──► SCAN_JOG
                           ▲                                               │
                           │        tag found OR max_mm OR print starts   │
                           └───────────────────────────────────────────────┘
```

When scan mode starts, the poll timer is parked at `NEVER` and `_scan_timer` takes over. When scan mode ends, `_scan_timer` returns `NEVER` and the poll timer is resumed.

---

## Instance State Variables

```python
# Class variable — shared across all NFCGate instances
NFCGate._active_scan_gate = None   # gate number holding the scan lock, or None

# Timers
self._scan_timer           = None      # registered only during active scan

# Scan mode
self._scan_mode            = False
self._scan_mm_total        = 0.0       # mm jogged forward so far
self._scan_next_chunk_time = 0.0       # reactor timestamp when next jog chunk may fire
self._scan_found_event     = None      # cached event suppressed during jog; dispatched after rewind

# Left-neighbor interference mitigation
self._scan_left_neighbor_gate = -1
self._scan_left_neighbor_shift_mm = 0.0
self._scan_left_neighbor_shifted = False
self._scan_left_neighbor_uid = None
self._scan_left_neighbor_attempts = 0

# Trigger detection
self._prev_gate_status     = -1        # -1 = cold start (no 0→1 false trigger)
self._scan_pending         = False     # armed on 0→1; fires when HH confirms idle
self._scan_idle_ready_time = 0.0       # timestamp for 2s HH-idle settle delay
```

---

## Config Keys

All added to `[nfc_gate]` (overridable per `[nfc_gate laneN]`):

| Key | Python fallback | Shipped `nfc_reader.cfg` | Meaning |
|---|---|---|---|
| `scan_enabled` | `True` | `False` | Controls the automatic gate-status trigger; `JOG_SCAN` still works when false |
| `scan_jog_mm` | `50.0` | `75.0` | Logical filament advance per scan chunk (mm), divided into three stopped-position substeps |
| `scan_reads_per_position` | `3` | `3` | NFC read attempts at each stopped spool position before moving the next substep |
| `scan_decode_retry_mm` | `2.0` | `2.0` | Distance between nearby retry positions |
| `scan_decode_retry_rounds` | `5` | `5` | Nearby retry rounds before accepting the current result |
| `scan_poll_interval` | `0.1` | `0.1` | Seconds between stopped-position NFC reads during scan |

`scan_jog_mm` of 25 mm gives a ~5 cm read window (25 mm on each side of center plus the antenna width) for finding tags that are slightly off-axis.
The maximum scan distance is read at scan start from Happy Hare's
`mmu_calibration_bowden_lengths` in `mmu_vars.cfg`; the current gate indexes
that list.

---

## Implementation: `scan_jog.py`

### `start(gate, max_mm)` — enter scan mode

```python
def start(gate, max_mm=None):
    gate.__class__._active_scan_gate = gate._gate
    gate._scan_mode = True
    gate._scan_mm_total = 0.0
    gate._scan_next_chunk_time = gate.reactor.monotonic()
    gate._hh_seed_spool_id = None     # clear startup seed — scan must re-read
    gate._hh_seed_available = False
    gate._scan_found_event = None

    gate._scan_hh_prep_pending = True

    gate._scan_timer = gate.reactor.register_timer(
        gate._scan_step_event,
        gate.reactor.monotonic())
```

**`GateState.reset()`** clears `_current_uid`, `_current_spool`, `current_tag`, and `miss_count` atomically (bypassing property setters). This forces `process_read` to fire a `changed` event on the first NFC read during scan, regardless of what was previously cached. The previous uid/spool are saved to `_scan_previous_uid`/`_scan_previous_spool` before the reset for reference during the abort path.

**Pre-scan clearing sequence:**

`start()` marks HH prep pending instead of running it synchronously. The first scan timer step consumes `_scan_hh_prep_pending`, then calls `clear_hh_gate_cache` and `sync_spoolman_before_scan` before polling and before the first jog move. This keeps the required HH state updates while avoiding reentrant `gcode.run_script()` calls from inside the Happy Hare hook stack.

`clear_hh_gate_cache` issues `_NFC_GATE_CLEAR_CACHE GATE=N`. That macro calls `MMU_GATE_MAP GATE=N SPOOLID=-1 AVAILABLE=1 QUIET=1`, so Happy Hare keeps the gate loaded while clearing the stale spool assignment before scan-jog resolves the current spool. It deliberately does not write placeholder `NAME`, `MATERIAL`, or `COLOR` fields, because those can persist in Happy Hare after the real spool id is assigned.

If scan-jog cannot resolve a spool id, stale filament metadata is cleared at the unresolved exit instead of at scan start. A tag that reads but has no Spoolman match dispatches `_NFC_TAG_NO_SPOOL ... SCAN_FINISH=1`; a scan that finds no tag calls `_NFC_SCAN_UNRESOLVED GATE=N` after rewind. Both paths clear `NAME`, `MATERIAL`, `COLOR`, and `TEMP` without dumping the full Happy Hare gate map.

`sync_spoolman_before_scan` pushes the cleared HH gate state to Spoolman via `MMU_SPOOLMAN SYNC=1`, vacating the spool's location field before the jog begins.

| Trigger | `clear_hh_gate_cache` | `sync_spoolman_before_scan` |
|---|---|---|
| Automatic `0→1` poll | runs from scan timer | runs from scan timer |
| Manual `NFC JOG_SCAN=1` | runs from scan timer | runs from scan timer |
| HH post-preload hook | runs from scan timer | runs from scan timer |

When the scan succeeds, `finish()` dispatches `_NFC_SPOOL_CHANGED ... SCAN_FINISH=1` after rewind. The macro assigns the identified spool and runs `MMU_SPOOLMAN SYNC=1`. `SCAN_FINISH` remains on the event as a compatibility marker, but the default macros do not print the full Happy Hare gate map.

### `step_event(gate, eventtime)` — the loop body

```python
def step_event(gate, eventtime):
    if not gate._scan_mode:
        return gate.reactor.NEVER

    if is_printing(gate):
        gate._rewind_and_exit_scan()
        return gate.reactor.NEVER

    now = gate.reactor.monotonic()
    tag_found = gate._poll()

    if tag_found and handle_left_neighbor_interference(gate, now):
        return gate.reactor.monotonic() + gate._scan_poll_interval

    if tag_found:
        if retry_incomplete_decode(gate, now):
            return gate.reactor.monotonic() + gate._scan_poll_interval
        gate._finish_scan()
        return gate.reactor.NEVER

    if gate._scan_mm_total >= gate._scan_max_mm:
        gate._rewind_and_exit_scan()
        return gate.reactor.NEVER

    # Jog only when the previous chunk is estimated complete; poll every tick.
    if now >= gate._scan_next_chunk_time:
        remaining = gate._scan_max_mm - gate._scan_mm_total
        chunk = min(gate._scan_jog_mm, remaining)
        gate._run_jog(chunk)
        gate._scan_mm_total += chunk
        gate._scan_next_chunk_time = now + chunk_interval(gate, chunk)

    return now + gate._scan_poll_interval
```

The timer always returns `now + scan_poll_interval` so NFC is polled continuously throughout the scan. Jog chunks are gated by `_scan_next_chunk_time`, which advances by `chunk_interval = abs(mm) / gear_short_move_speed` after each issue. This decouples read frequency from motor timing — the tag can be detected anywhere in the move, not only after the chunk completes.

### `finish(gate)` — tag found

When a UID is detected but the rich payload read is marked incomplete, scan-jog queues nearby retry jogs before accepting the current UID/metadata result. The retry decision is format-neutral: reader/parser code sets `CurrentTag.read_incomplete` and `read_retry_reason`; scan-jog only applies the configured `scan_decode_retry_mm` / `scan_decode_retry_rounds` policy. Each retry round probes both sides of the first UID hit position. The first implementation marks incomplete MIFARE reads when sector authentication or block reads fail, which covers spool-mounted Bambu tags at the edge of the reader field.

### Left-neighbor interference

Some tagged spools expose a tag on both sides. With the PN532 mounted on the
left side of each lane, gate `N` can occasionally see the parked spool on gate
`N - 1` during scan-jog. The mitigation is intentionally narrow:

- only active during scan-jog
- only checks the immediate left neighbor
- only treats a read as interference when the read UID exactly matches the
  left NFC gate object's cached UID
- never compares Spoolman spool IDs or Happy Hare display metadata

When the match is confirmed, scan-jog selects the left gate, moves it forward
75 mm, waits with `M400`, reselects the current gate, clears the false scan
result, and reads again. If the same left-neighbor UID is still visible, it may
repeat that clearance move up to three total times. The current gate's
`_scan_mm_total` is unchanged because the current spool did not move.

If the reader still sees the same left-neighbor UID after the third clearance
move and follow-up read, scan-jog emits an `[ERROR]`, exits through the normal
rewind path, and restores the left neighbor by the accumulated clearance
distance. It does not assign the neighbor spool to the current lane.

Both successful and aborted scan exits call `restore_left_neighbor()` after the
current gate rewind is queued:

```gcode
MMU_SELECT GATE=<left>
MMU_TEST_MOVE MOVE=-75.00 QUIET=1
M400
MMU_SELECT GATE=<current>
```

```python
def finish(gate):
    gate._scan_mode = False
    gate.__class__._active_scan_gate = None
    gate._state.miss_count = 0
    gate._run_rewind()
    # Dispatch the spool event that was suppressed while the filament was moving.
    if gate._scan_found_event is not None:
        event_type, g, uid, spool = gate._scan_found_event
        gate._scan_found_event = None
        gate._klipper.dispatch(event_type, g, uid, spool)
    gate._resume_poll_after_rewind()
```

### `rewind_and_exit(gate)` — abort path

```python
def rewind_and_exit(gate):
    gate._scan_mode = False
    gate.__class__._active_scan_gate = None
    gate._state.miss_count = 0
    gate._run_rewind()
    gate._resume_poll_after_rewind()
```

`resume_poll_after_rewind` restarts the poll timer with an extra delay equal to the rewind move duration (`scan_mm_total / speed`) so the first scheduled poll fires after the rewind is complete.

### `run_jog(gate, mm)` — jog primitive

```python
def run_jog(gate, mm):
    gcode = gate.printer.lookup_object('gcode')
    gcode.run_script("MMU_TEST_MOVE MOVE=%.2f QUIET=1" % mm)
```

`MMU_SELECT GATE=N` is issued once in `start()` before the scan timer fires. `run_jog` issues only `MMU_TEST_MOVE` since the gate context is already set. `QUIET=1` suppresses HH console output.

### `run_rewind(gate)` — rewind primitive

```python
def run_rewind(gate):
    if gate._scan_mm_total <= 0.0:
        return
    gcode = gate.printer.lookup_object('gcode')
    gcode.run_script("MMU_TEST_MOVE MOVE=%.2f QUIET=1\nM400"
                     % -gate._scan_mm_total)
```

Rewind is dead-reckoning: a negative `MMU_TEST_MOVE` of exactly `scan_mm_total`. `M400` (wait for moves) is appended so the reactor timer knows the rewind is physically complete before the next poll fires.

---

## Timer Lifecycle

| Timer | Created | Destroyed | Interval |
|---|---|---|---|
| `_poll_timer` | `__init__` (parked at NEVER) | `_handle_disconnect` | `poll_interval` (default 10 s) |
| `_scan_timer` | `start()` | `step_event()` returns NEVER | `scan_poll_interval` |

The scan timer is created anew on each scan entry. Returning `reactor.NEVER` from `step_event` parks it permanently. `_scan_mode = False` is the canonical in-flight abort flag.

---

## GateState Interaction

`step_event` calls `gate._poll()` directly — the same method the poll timer fires. `_poll()` runs the full state machine including Spoolman lookup and `GateState.process_read`. When `_poll()` returns `True` (tag found), `step_event` calls `finish()` immediately.

**Event dispatch is deferred during scan.** If a spool-changed event fires while `_scan_mode` is True (filament is still moving), `NFC_manager` caches it in `_scan_found_event` instead of dispatching immediately. `finish()` dispatches the cached event after `run_rewind()` returns, so HH and Spoolman receive the notification only after the filament is back at the parked position.

`GateState.miss_count` does **not** increment during scan ticks. `process_read()` receives `scan_mode=True` when called from within scan mode — the miss path is skipped for no-read results. A missed NFC read during a deliberate spool rotation is not an absence event.

---

## Interaction with `_hh_load_paused`

When `_poll()` identifies a tag during a scan step, `GateState.process_read` sets `current_uid` and `current_spool` but `KlipperInterface.dispatch` is suppressed — the event is cached in `_scan_found_event`. After the rewind completes, `finish()` dispatches `_NFC_SPOOL_CHANGED`; HH sets `gate_spool_id[N] > 0`. When the poll timer resumes, the first tick sees `_hh_gate_matches_current_spool()` returning True and enters the normal suspended state.

---

## Logging

Scan-jog messages follow the standard debug level conventions:

| Message | Level gate | `nfc_reader.log` | `klippy.log` |
|---|---|---|---|
| `scan mode started — chunk=Xmm max=Xmm speed=Xmm/s` | `debug >= 3` | ✅ | ❌ |
| `gate loaded; waiting for HH idle before scan` | `debug >= 3` | ✅ | ❌ |
| `HH idle; waiting 0.1s before scan-jog` | `debug >= 3` | ✅ | ❌ |
| `scan preflight — lane N gate_status=X safe/not safe` | `debug >= 3` | ✅ | ❌ |
| `scan trigger deferred: gate N already scanning` | `debug >= 3` | ✅ | ❌ |
| `starting scan-jog (max=Xmm poll=Ys)` | `debug >= 3`; console always | ✅ | ❌ |
| `scan-jog not available while reason` | warning (always) | ✅ | ✅ |
| `tag identified — rewinding Xmm` | `info` (always) | ✅ | ❌ |
| `rewind complete; gate parking handed to Happy Hare` | `info` (always) | ✅ | ❌ |
| `no tag — jogged Xmm / Xmm` | `info` (always at each step) | ✅ | ❌ |
| `print started — aborting` | warning (always) | ✅ | ✅ |
| `no tag after Xmm — rewinding` | warning (always) | ✅ | ✅ |

Set `debug: 3` to observe scan start and success. Set `debug: 4` for full poll detail during scans.

---

## Happy Hare Compatibility Notes

- `MMU_SELECT GATE=N` and `MMU_TEST_MOVE MOVE=mm QUIET=1` are standard Happy Hare v2.x commands.
- `get_speed()` reads `mmu.gear_short_move_speed` from the HH Python object to compute chunk timing. Falls back to 80 mm/s if the attribute is absent.
- `mmu.get_status()['gate_status']` values: `0` = empty, `1` = available/parked, `2` = available from buffer. Scan mode triggers only on `0 → 1`. Buffer-loaded filament (`0 → 2`) does not trigger.
- `mmu.get_status()['action']` is lowercased and compared `== 'idle'` (exact). If HH changes its action string, the guard silently prevents scan mode from starting (safe-fail direction).

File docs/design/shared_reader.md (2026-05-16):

# Design: Shared Reader

> Status: In progress
> Scope: No IRQ/data-ready pin support in this phase.

---

Implementation status and audit notes live in [shared_reader_implementation.md](shared_reader_implementation.md).
User-facing console and log output is defined in
[message_definition.md](../shared/message_definition.md).

---

## Goal

Add one NFC reader inside the MMU body that is **not tied to an EMU lane**.
The reader acts as a staging point for the next manually loaded spool:

1. User taps a tag on the hidden MMU reader.
2. NFC resolves the tag to a Spoolman spool ID, creating the spool first if
   `spoolman_auto_create` is enabled and the tag carries enough metadata.
3. NFC gives user feedback through LEDs.
4. User loads a spool through the normal MMU/pre-gate path.
5. Happy Hare assigns the staged spool ID to whichever gate is preloaded next.

Happy Hare already has the desired primitive:

```gcode
MMU_GATE_MAP NEXT_SPOOLID=<spool_id>
```

If a gate is preloaded within Happy Hare's timeout window after that command,
HH assigns that spool ID to the loaded gate. The shared reader should use that
mechanism instead of trying to determine the destination gate itself.

---

## Non-goals

- Do not make the shared reader part of the EMU lane reader set.
- Do not add PN532 IRQ/data-ready support yet.
- Do not scan-jog from the shared reader.
- Do not infer gate assignment by inspecting NFC gate polling state.
- Do not duplicate Spoolman create/lookup logic already used by lane readers.
- Do not duplicate the existing NFC reader timer, read, resolve, debounce, or
  debug command machinery.
- Do not call Happy Hare Python internals directly. Use HH's public GCode
  command surface.

---

## Key Decision

Use a normal `NFCGate` instance for the physical reader and put it in shared
mode. The reader is configured as `[nfc_gate shared]` with `shared: true`.
No `mmu_gate` value is needed or accepted from the user — the shared reader has
no Happy Hare gate assignment. An internal sentinel (255) is used only for
PN532Driver and GateState logging and is never passed to Happy Hare.

**No per-lane readers are required.** A shared-only installation needs only the
base `[nfc_gate]` section (optional, for Spoolman config) and the
`[nfc_gate shared]` section. No `[nfc_gate lane0]` or similar sections are
needed.

The shared reader has no physical EMU lane, so its dispatch behavior differs
from a normal lane:

```text
lane reader:
  physical gate -> read tag -> resolve spool -> assign that same gate

shared reader:
  existing NFCGate poll -> resolve spool -> remember pending spool
  preload hook -> stage NEXT_SPOOLID
```

That means the shared reader only needs to know:

- the most recently scanned spool ID
- whether that staged spool is still within the timeout window

It does **not** need to know:

- which gate is currently loaded
- which gate is about to preload
- whether an EMU lane reader is paused
- whether a lane reader has cached NFC state

The preload hook is primarily a timing signal. NFC should wait until Happy Hare
reports that a pregate-triggered preload is about to start, then issue
`MMU_GATE_MAP NEXT_SPOOLID=<id>` if a valid pending spool exists. Happy Hare
still decides which gate receives that staged spool.

`shared` is the NFC object name. Scan-jog edge detection and HH gate-map
matching are disabled for this reader. All user interaction goes through
`NFC_SHARED`.

---
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

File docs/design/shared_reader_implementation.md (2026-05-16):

# Implementation: Shared Reader

> Companion implementation/audit tracker for `docs/design/shared_reader.md`.
> The design document describes the intended behavior; this file tracks
> what the current code and docs implement.

---

> Working memory for auditing the shared reader implementation against
> `docs/design/shared_reader.md`.
>
> Green means the current tree has an implementation matching the baseline.
> Red means the item is missing, incomplete, or still requires validation.
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

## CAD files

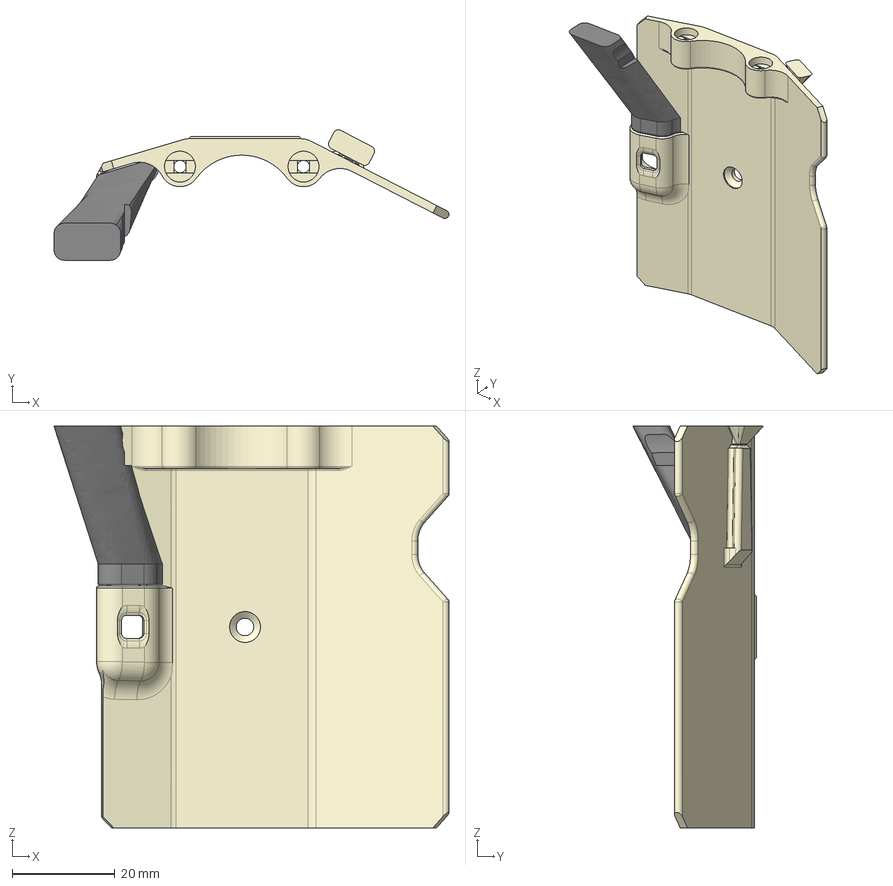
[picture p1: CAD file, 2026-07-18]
NFC Mounting Bracket/LED_holder_for_EMU_NFC_Reader_Board.step
76.7 x 25.4 x 78.0 mm

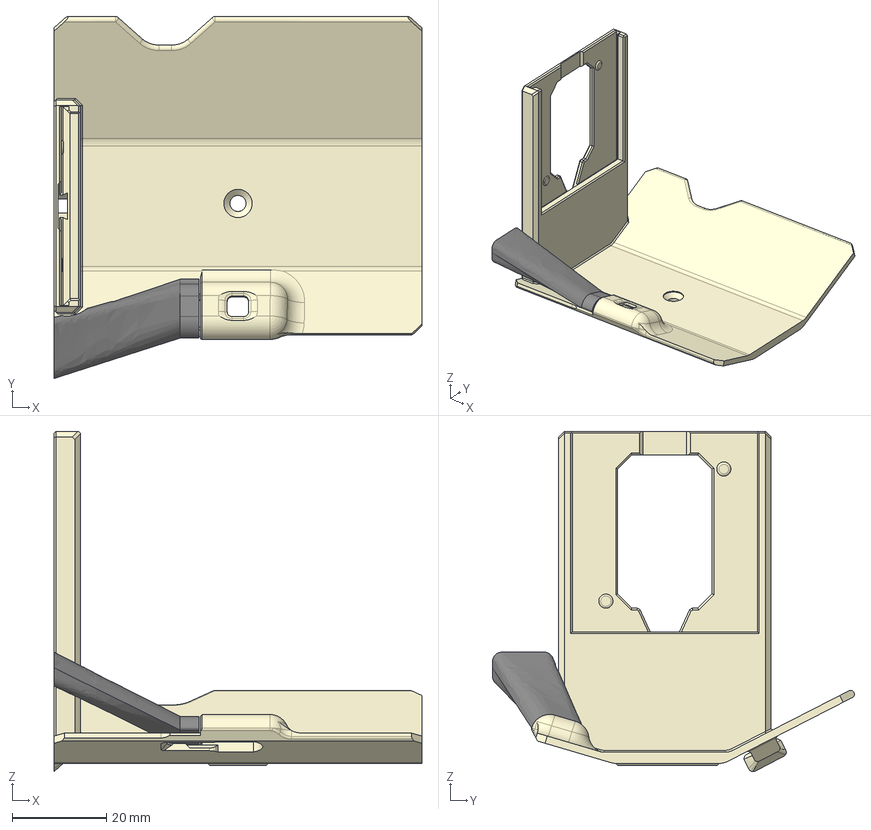
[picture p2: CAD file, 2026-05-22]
NFC Mounting Bracket/LED_holder_v3_for_EMU_PN532.step
78.0 x 76.7 x 72.2 mm

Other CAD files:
NFC Mounting Bracket/LED_holder_for_EMU_NFC_Reader_Board.stl
NFC Mounting Bracket/LED_holder_v3_for_EMU_PN532.stl

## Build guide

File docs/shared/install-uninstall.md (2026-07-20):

# Install & Uninstall

[← README](../../Readme.md) | [Wiring](../i2c-nfc/wiring.md) | [Setup →](../i2c-nfc/setup.md)

---

## How the Install Works

The installer creates **symlinks** — it does not copy Python files into the Klipper directory. This means:

- Normal updates are installed from Moonraker's web interface in Mainsail or Fluidd
- Reader and hardware config files in `~/printer_data/config/nfc/` are yours and are not changed during updates or repair
- `nfc_macros.cfg` is a read-only link and updates with the project
- `bash install.sh -r` repairs installer-owned links and integration files without rewriting user settings
- `bash install.sh --reconfigure` backs up the NFC configuration and reruns the setup wizard

**What gets created:**

```
~/klipper/klippy/extras/nfc_gate.py         →  symlink → repo/klippy/extras/nfc_gate.py
~/klipper/klippy/extras/nfc_gates/          →  symlink → repo/klippy/extras/nfc_gates/
~/klipper/klippy/extras/mmu_nfc_endstop.py  →  symlink → repo/klippy/extras/mmu_nfc_endstop.py
~/printer_data/config/nfc/nfc_reader.cfg
~/printer_data/config/nfc/nfc_macros.cfg          →  symlink → repo/config/nfc_macros.cfg
~/printer_data/config/nfc/nfc_reader_hw.cfg
~/printer_data/config/nfc/nfc_reader_shared.cfg
```

`mmu_nfc_endstop.py` registers each enabled lane's NFC reader as a Happy Hare
gear-rail homing endstop. `nfc_reader_hw.cfg` gets one `[mmu_nfc_endstop
laneN]` section per enabled lane automatically, alongside the matching
`[nfc_gate laneN]` — see [Virtual Endstop](../shared/klipper-functions.md#virtual-endstop).

The interactive installer runs once. It creates user-owned configuration with a non-destructive merge, adds the ordered NFC includes to `printer.cfg`, configures Moonraker, and records the completed installation in `nfc/.install-state`. Later runs exit without changing configuration. Use `bash install.sh -r` only to repair installer-owned links, includes, the update-manager section, or the state marker. Use `bash install.sh --reconfigure` when you intentionally want to rerun the wizard; it creates a timestamped copy of the complete NFC configuration first.

---

## Install

### Step 1 — Flash Lane MCU Firmware

> [!CAUTION]
> Do this before anything else. The NFC reader driver communicates directly with the MCU firmware over I2C. If the host Klipper and the MCU firmware are on different versions, I2C reads fail with errors that look like hardware faults.
>
> Build and flash Klipper firmware for every MCU that will carry an NFC reader before you run the installer.

### Step 2 — Clone the Repository

SSH to the Pi:

```bash
cd ~
git clone https://github.com/cwiegert/Happy-Hare-RFID-Reader.git rfid-reader
cd ~/rfid-reader
```

The installer configures a sparse checkout automatically — documentation and other non-runtime files are excluded from the Pi.

> [!IMPORTANT]
> Beta cutover: old `~/emu-nfc-reader` installs are not migrated in place. Clone this repo into `~/rfid-reader` and run `bash install.sh`. If the installer finds `~/emu-nfc-reader`, it prompts before backing up `~/printer_data/config/nfc/`, backing up `moonraker.conf`, removing the old Moonraker update-manager block, removing the old clone, and continuing with a fresh install.

### Step 3 — Run the Installer

```bash
bash install.sh
```

The installer prints what it creates. If it cannot find the Klipper extras directory or the printer config directory, it exits with an error before making any changes.

For per-lane readers, the installer asks for the Happy Hare version. Select
`v3` for the conventional `lane0` / `mmu0` layout. Select `v4` for Happy Hare
V4's default single-unit layout; it creates matching `unit0_laneN`,
`unit0_gateN`, and `nfc_unit0_laneN` sections. The V4 option deliberately
uses only the standard `unit0` layout. Multi-unit or custom gate mappings must
be edited in `nfc_reader_hw.cfg` after installation.

### Step 4 — Verify Includes in `printer.cfg`

The installer backs up `printer.cfg` and adds the matching includes in this order. Verify them after installation.

Per-lane readers:

```ini
[include nfc/nfc_reader.cfg]
[include nfc/nfc_macros.cfg]
[include nfc/nfc_reader_hw.cfg]
```

Shared-reader-only:

```ini
[include nfc/nfc_reader.cfg]
[include nfc/nfc_macros.cfg]
[include nfc/nfc_reader_shared.cfg]
```

Hybrid:

```ini
[include nfc/nfc_reader.cfg]
[include nfc/nfc_macros.cfg]
[include nfc/nfc_reader_hw.cfg]
[include nfc/nfc_reader_shared.cfg]
```

Order is required. `nfc_reader.cfg` defines the base `[nfc_gate]` section that each lane section inherits from. Including the lane file first causes a Klipper startup error.

### Step 5 — Verify Spoolman

The installer writes the selected Spoolman mode to `~/printer_data/config/nfc/nfc_reader.cfg`. Verify it after installation:

```ini
[nfc_gate]
spoolman_url:      auto
spoolman_rfid_key: rfid_tag
```

**`spoolman_url: auto`** works when Moonraker has a `[spoolman]` section configured. Use a direct URL if you need to point at a specific instance:

```ini
spoolman_url: http://192.168.1.50:7912
```

See [Spoolman Integration](spoolman-integration.md) for how to create the extra field and register UIDs.

### Step 6 — Configure Lane Hardware

Edit `~/printer_data/config/nfc/nfc_reader_hw.cfg`. The default file has four lanes — adjust the MCU names and gate numbers to match your Happy Hare setup:

```ini
[nfc_gate lane0]
enabled: True
mmu_gate: 0
i2c_mcu:  mmu0
```

`i2c_mcu` must exactly match the MCU name in your Happy Hare config (from `mmu_hardware.cfg`), typically `mmu0`, `mmu1`, etc. `i2c_bus` can be set once in the base `[nfc_gate]` section or overridden per lane. RC522 and PN5180 use SPI settings instead; PN5180 additionally requires wired `reset_pin` and active-high `busy_pin`. See [PN5180 wiring](../i2c-nfc/pn5180-wiring.md) for the SLB nine-wire example.

> [!IMPORTANT]
> **Temperature sensor I2C bus must match.** If your lane MCU also has a thermistor or temperature sensor connected over I2C (e.g. an SHT3x), configure it on the same I2C bus as the NFC reader. PN532 should use hardware I2C. PN7160 supports software I2C, but hardware I2C is recommended because software I2C increases MCU load.

See [Configuration Reference](configuration.md) for all available settings.

### Step 7 — Restart and Verify

```bash
sudo systemctl restart klipper
```

```gcode
NFC_STATUS
NFC_DOCTOR
```

Expected output with no tags loaded:

```
NFC gate status  (4 gates configured):
  Gate 0  [lane0]:  empty
  Gate 1  [lane1]:  empty
  Gate 2  [lane2]:  empty
  Gate 3  [lane3]:  empty
```

If you see errors, check [Troubleshooting](../i2c-nfc/troubleshooting.md).

---

### Per-Lane Readers — Required Hook

Wire the Happy Hare post-preload hook so scan-jog triggers automatically after each preload. This requires the [igiannakas IG-dev branch](https://github.com/igiannakas/Happy-Hare/tree/IG-dev) of Happy Hare, which adds `variable_user_post_preload_extension` to `mmu_macro_vars.cfg`.

**Wire the scan-jog hook.** Open `~/printer_data/config/mmu/base/mmu_macro_vars.cfg` and add:

```ini
[gcode_macro _MMU_SEQUENCE_VARS]
variable_user_post_preload_extension: '_NFC_SCAN_JOG_PRELOAD'
```

Happy Hare appends `GATE=<n>` automatically. `_NFC_SCAN_JOG_PRELOAD` calls `NFC GATE=<n> JOG_SCAN=1 SOURCE=AUTO`; NFC starts the configured scan-jog LED effect from the Python scan timer before motion begins. With this wired, set `scan_enabled: False` so Happy Hare is the sole scan-jog trigger:

```ini
[nfc_gate]
scan_enabled: False
```

`SOURCE=AUTO` identifies this as Happy Hare's own hook call. Happy Hare v4 can
run the hook while its action is still `checking`, before it unwinds back to
`idle`, so NFC runs hook calls through the version-aware scan-safe check.
Manual or console `JOG_SCAN=1` commands without `SOURCE=AUTO` still require
strict `action=idle`.

Without this hook wired, scan-jog falls back to triggering on gate status change (`scan_enabled: True`), which is less reliable than the preload hook.

---

### Shared Reader — Additional Required Steps

If you are using the shared reader (`[nfc_gate shared]`), two more things must be configured before it will work. Both require the [igiannakas IG-dev branch](https://github.com/igiannakas/Happy-Hare/tree/IG-dev) of Happy Hare, which adds `variable_user_post_preload_extension` to `mmu_macro_vars.cfg`.

**Wire the Happy Hare preload hook.** Open `~/printer_data/config/mmu/base/mmu_macro_vars.cfg` and add:

```ini
[gcode_macro _MMU_SEQUENCE_VARS]
variable_user_post_preload_extension: '_NFC_SHARED_PRELOAD'
```

For a hybrid installation that also has per-lane readers, use this instead:

```ini
variable_user_post_preload_extension: '_NFC_HYBRID_PRELOAD'
```

`_NFC_HYBRID_PRELOAD` starts a configured lane reader first. If the lane scan
cannot read a tag, it applies staged shared-reader data to the loaded gate.
It uses the shared reader directly for a gate without a lane reader.

Without this, NFC never sees the preload event and the spool ID is never applied to the gate.

If this value is still set to `NFC JOG_SCAN=1`, the printer is using the per-lane reader hook. Shared-reader loads will stage a spool, but the post-preload commit will not run; the pending spool will eventually time out and you may see `NFC GATE=<n>` errors.

**Pending timeout.** NFC uses Happy Hare's active `[mmu]`
`pending_spool_id_timeout` when Klipper exposes that value. Otherwise it uses
its 60 s default. No additional Happy Hare configuration is required for the
default behavior.

---

## Moonraker Update Manager

The installer adds this block to `~/printer_data/config/moonraker.conf` automatically. If it was not found or you need to add it manually:

```ini
[update_manager Happy-Hare-RFID-Reader]
type:             git_repo
channel:          dev
path:             ~/rfid-reader
origin:           https://github.com/cwiegert/Happy-Hare-RFID-Reader.git
primary_branch:   main
managed_services: klipper
```

Restart Moonraker:

```bash
sudo systemctl restart moonraker
```

> [!NOTE]
> Moonraker updates the Git checkout and restarts Klipper; it does not rerun the interactive installer. You still need to **manually rebuild and flash lane MCU firmware** when a Klipper MCU protocol change is included in an update — the update notes will say so.

---

## Updating

Use the Update Manager in Mainsail or Fluidd and select **Update** for Happy Hare RFID Reader. Moonraker pulls the update and restarts Klipper automatically.

If installer-owned links or integration files are damaged, repair them explicitly:

```bash
cd ~/rfid-reader
bash install.sh -r
```

To change the reader layout or installer-managed setup choices, rerun the wizard explicitly:

```bash
cd ~/rfid-reader
bash install.sh --reconfigure
```

The wizard saves the previous configuration as `~/printer_data/config/nfc_pre_reconfigure_<timestamp>` before applying any selected values.

If the update notes mention a Klipper MCU protocol change, rebuild and flash each lane MCU before restarting Klipper.

---

## Uninstall

```bash
cd ~/rfid-reader
bash uninstall.sh
```

The uninstaller:

1. Removes the `nfc_gate.py` symlink from Klipper extras
2. Removes the `nfc_gates/` symlink from Klipper extras
3. Removes legacy `~/pn532_scan.py` if an older installer placed it there
4. Removes the `mmu_nfc_endstop.py` symlink from Klipper extras
5. Moves `~/printer_data/config/nfc/` to `nfc_removed_<timestamp>/` (your config is preserved, not deleted)
6. Restarts Klipper

At the end, it prompts whether to remove the local repo checkout at
`~/rfid-reader`. The default answer is yes. Answer `n` to keep the checkout.

**Manual steps after uninstalling** — the uninstaller cannot edit your config files:

Remove these three lines from `printer.cfg`:
```ini
[include nfc/nfc_reader.cfg]
[include nfc/nfc_macros.cfg]
[include nfc/nfc_reader_hw.cfg]
```

Remove the update manager block from `moonraker.conf`, then restart Moonraker:

```ini
[update_manager Happy-Hare-RFID-Reader]
```

If you are cleaning up an earlier beta, also remove either old block if present:

```ini
[update_manager emu_nfc_reader]
[update_manager happy_hare_rfid_reader]
[update_manager Happy-Hare-rfid-reader]
```

```bash
sudo systemctl restart moonraker
```

Delete the config backup when you no longer need it:
```bash
rm -rf ~/printer_data/config/nfc_removed_*
```

---

*Copyright (C) 2026 WoodWorker. Licensed under [GPL-3.0-or-later](https://www.gnu.org/licenses/gpl-3.0.html) — see [LICENSE](../../LICENSE).*

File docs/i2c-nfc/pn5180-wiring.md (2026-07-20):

# Wiring the PN5180

[NFC Reader Wiring](wiring.md) | [Configuration](../shared/configuration.md) | [Setup](setup.md)

PN5180 is an SPI NFC controller. In this project it supports ISO14443A tags
(including NTAG and authenticated MIFARE/Bambu reads) and SLIX2
(ISO15693/Type-5) tags.
It can be configured as a shared reader or as a per-lane reader with
`reader_type: pn5180`.

SLIX2 support is not limited to OpenPrintTag. After the Type-5 user memory is
read, the reader path removes the Type-5 Capability Container when present and
passes the remaining bytes to the normal tag parser. The payload is therefore
handled according to its actual supported format, not a reader-specific format.

This page uses the Happy Hare SLB/MMU board as a concrete wiring example. Pin
names and power connectors vary on other boards; use their equivalent MCU GPIO
and power connections instead.

## Required Connections

The PN5180 setup requires all nine connections below. `BUSY` and `RST` are not
optional: the driver waits for the active-high BUSY signal around every command
and uses RST to recover a reader that has stopped responding.

| PN5180 module pin | SLB/MMU connection | Config setting | Required purpose |
|---|---|---|---|
| `SCK` | `PB13` | `spi_bus: spi2_PB14_PB15_PB13` | SPI clock |
| `MISO` | `PB14` | `spi_bus: spi2_PB14_PB15_PB13` | SPI data from reader |
| `MOSI` | `PB15` | `spi_bus: spi2_PB14_PB15_PB13` | SPI data to reader |
| `NSS` / `CS` | `PA8` | `cs_pin: mmu:PA8` | SPI chip select |
| `BUSY` | `PB0` | `busy_pin: mmu:PB0` | Active-high command-complete signal |
| `RST` | `PC6` | `reset_pin: mmu:PC6` | MCU-controlled hardware reset |
| `5V` | SLB/MMU 5V supply | - | RF/front-end power |
| `3.3V` | **PSF connector 3.3V** | - | Logic/SPI power; must be connected |
| `GND` | SLB/MMU GND | - | Common ground |

> [!IMPORTANT]
> The PN5180 breakout used for this wiring needs both `5V` and `3.3V`. Do not
> omit the 3.3V wire or replace it with 5V. Connect its 3.3V pin to the PSF
> connector's 3.3V supply, and ensure every signal shares the same ground.

The module's `IRQ`, `GPIO`, and `AUX` pins are not used by the current driver.
It polls the PN5180 internal IRQ status through SPI, so leave those pins
unconnected unless another circuit requires them.

## SPI Speed

Both PN5180 and RC522 default to `spi_speed: 500000` with hardware SPI. This is
a conservative starting point for MMU wiring. Software SPI can also be used
when the MCU has no suitable hardware bus, but set `spi_speed: 100000` because
bit-banged SPI is less tolerant of high rates.

## Shared Reader Configuration

Put this in `[nfc_gate shared]` in `nfc_reader_shared.cfg` for the SLB wiring
above. Keep the existing `i2c_mcu: mmu` line in the section; it identifies the
reader's Klipper MCU even though the PN5180 itself uses SPI.

```ini
[nfc_gate shared]
enabled:                True
reader_type:            pn5180
i2c_mcu:                mmu
spi_bus:                spi2_PB14_PB15_PB13
cs_pin:                 mmu:PA8
reset_pin:              mmu:PC6
busy_pin:               mmu:PB0
spi_speed:              500000
shared:                 true
startup_polling:        1
```

`reset_pin` has no implicit fallback and must be present in the configuration.
`busy_pin` defaults to `mmu:PB0`, but explicitly setting it is recommended so
the configured wire is clear. The BUSY wire itself is mandatory in either case.

## Per-Lane Configuration

Use the same reader-specific settings in the matching lane section. Replace the
MCU prefix and SPI bus with the actual lane MCU wiring.

```ini
[nfc_gate lane0]
enabled:                True
reader_type:            pn5180
mmu_gate:               0
i2c_mcu:                mmu
spi_bus:                spi2_PB14_PB15_PB13
cs_pin:                 mmu:PA8
reset_pin:              mmu:PC6
busy_pin:               mmu:PB0
spi_speed:              500000
```

For software SPI, replace `spi_bus` with Klipper's
`spi_software_sclk_pin`, `spi_software_mosi_pin`, and
`spi_software_miso_pin` settings, retain `cs_pin`, `busy_pin`, and `reset_pin`,
and set `spi_speed: 100000`.

## Bring-Up Checks

1. Confirm all nine connections, especially both power rails and the common
   ground.
2. Confirm `BUSY` reaches the configured GPIO and is not inverted. It is
   active high.
3. Confirm `RST` reaches the configured GPIO; do not tie RST permanently high.
4. Confirm the selected SPI bus matches `PB13`/`PB14`/`PB15` on the SLB.
5. Restart Klipper and run `NFC_SHARED INIT=1` or `NFC GATE=<n> INIT=1`.
6. Run `NFC_SHARED SCAN=1` or `NFC GATE=<n> SCAN=1` with a tag nearby.

If the reader reports a BUSY timeout or invalid health registers, first check
the 3.3V wire, BUSY, RST, MISO, chip select, and common ground. A working reset
wire lets the driver recover from a communication lockup without unplugging the
module.

---

*Copyright (C) 2026 WoodWorker. Licensed under [GPL-3.0-or-later](https://www.gnu.org/licenses/gpl-3.0.html) - see [LICENSE](../../LICENSE).*

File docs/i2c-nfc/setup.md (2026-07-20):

# First-Time Setup

[← Install](../shared/install-uninstall.md) | [Spoolman Setup →](../shared/spoolman-integration.md)

This guide assumes you have:
- [Wired the NFC reader](wiring.md)
- [Installed the software](../shared/install-uninstall.md)
- Rebuilt and flashed Klipper firmware on every lane MCU

If you skipped any of those, do them first.

---

## Step 1 — Add Includes to `printer.cfg`

Add these three lines in this exact order:

```ini
[include nfc/nfc_reader.cfg]
[include nfc/nfc_macros.cfg]
[include nfc/nfc_reader_hw.cfg]
```

`nfc_reader.cfg` must come first — it defines the base `[nfc_gate]` section that each `[nfc_gate laneN]` in `nfc_reader_hw.cfg` inherits from. Reversing the order causes a Klipper config error on startup.

---

## Step 2 — Configure Spoolman

Edit `~/printer_data/config/nfc/nfc_reader.cfg`:

```ini
[nfc_gate]
spoolman_url:      auto
spoolman_rfid_key: rfid_tag
```

| Setting | Value | When to use |
|---|---|---|
| `spoolman_url: auto` | Reads URL from Moonraker | Use this when `moonraker.conf` has a `[spoolman]` section |
| `spoolman_url: http://host:7912` | Direct URL | Use when testing, or if `auto` isn't working |
| `spoolman_rfid_key: rfid_tag` | Extra field name | Must match what you create in Spoolman Settings |

See [Spoolman Integration](../shared/spoolman-integration.md) — you need to create the extra field in Spoolman and register each tag UID before spool detection will work.

---

## Step 3 — Configure Lane Hardware

Edit `~/printer_data/config/nfc/nfc_reader_hw.cfg`. The default file has four lanes; adjust to match your printer:

```ini
[nfc_gate lane0]
enabled:    True
mmu_gate:   0
i2c_mcu:    mmu0

[nfc_gate lane1]
enabled:    True
mmu_gate:   1
i2c_mcu:    mmu1
```

| Key | Required | Value |
|---|:---:|---|
| `mmu_gate` | Yes | Happy Hare gate number (0-based integer) |
| `i2c_mcu` | Yes | Klipper MCU name — must match an `[mcu laneN]` in your config |
| `enabled` | No | Defaults to `True`. Set `False` to keep a future lane template without creating hardware. |
| `reader_type` | Inherited unless overridden | `pn532` by default. Set `pn7160`, `rc522`, or `pn5180` for the installed reader. |
| `i2c_address` | Inherited unless overridden | PN532 uses `36`; PN7160 must use `40-43`. Not used by RC522 or PN5180. |
| `i2c_bus` | Inherited unless overridden | I2C bus name on that MCU — use `i2c3_PB3_PB4` for PB3/PB4 on EBB42 or set it once in `[nfc_gate]`. Not used by RC522 or PN5180. |

| `spi_bus`, `cs_pin`, `spi_speed` | SPI readers | Required for RC522 and PN5180. Use `500000` for hardware SPI or `100000` for software SPI. |
| `reset_pin`, `busy_pin` | PN5180 | Required PN5180 RST and active-high BUSY GPIO. See [PN5180 wiring](pn5180-wiring.md). |

> [!NOTE]
> `i2c_mcu` must exactly match the MCU name Klipper uses. These names come from Happy Hare's `mmu_hardware.cfg`, typically `lane0`, `lane1`, etc. A mismatch causes a Klipper startup error.

> [!IMPORTANT]
> **Temperature sensor I2C bus must match.** If your lane MCU has a thermistor or temperature sensor on I2C (e.g. an SHT3x), configure it on the **same I2C bus** as the NFC reader. PN532 should use hardware I2C. PN7160 supports software I2C, but hardware I2C is recommended because software I2C increases MCU load.

PN7160 lane example:

```ini
[nfc_gate lane1]
enabled:     True
reader_type: pn7160
i2c_address: 40
mmu_gate:    1
i2c_mcu:     mmu1
```

All polling, timing, and logging settings are inherited from the base `[nfc_gate]` in `nfc_reader.cfg`. Override per-lane only if you need different behavior on a specific lane:

```ini
[nfc_gate lane2]
enabled:    True
mmu_gate:   2
i2c_mcu:    mmu2
debug:      2              ; verbose logging on this lane only
```

---

## Step 4 — Restart Klipper

```bash
sudo systemctl restart klipper
```

Watch the log for NFC startup messages:

```bash
tail -f ~/printer_data/logs/nfc_reader.log
```

Errors at this stage are almost always config typos or a missing/mismatched lane MCU name.

---

## Step 5 — Verify Each Reader

### 1. Check all gates

```gcode
NFC_STATUS
```

Expected with no tags loaded:
```
NFC gate status  (4 gates configured):
  Gate 0  [lane0]:  empty
  Gate 1  [lane1]:  empty
  Gate 2  [lane2]:  empty
  Gate 3  [lane3]:  empty
```

### 2. Watch the startup console output

When Klipper connects, each lane initialises automatically and reports to the console. Look for:

```
[OK] NFC[lane0]: ready.  HH seed: spool_id=42  Startup polling is enabled; first poll in 0.0s.
```

or, if the gate was empty in Happy Hare:

```
[OK] NFC[lane0]: ready.  HH reports gate empty  Run NFC GATE=0 READ=1 to start polling.
```

**The HH seed line is important.** It means NFC_Manager read Happy Hare's gate map on startup and pre-loaded the lane cache with the spool HH already knows about. The first poll will verify the physical tag matches that spool — if it does, no redundant dispatch is sent to Happy Hare. If the spool was swapped while Klipper was down, the mismatch is detected and `_NFC_SPOOL_CHANGED` fires normally.

If Happy Hare wasn't ready when the NFC init ran, the seed step is skipped. Run `NFC_HH_SYNC_CACHE` to manually re-seed all lanes from the current HH gate map.

### 3. Initialize a lane manually

```gcode
NFC GATE=0 INIT=1
```

This runs the configured NFC reader initialization. Expected output:
```
[OK] NFC[lane0]: reader OK
```

If it fails, check [Troubleshooting](troubleshooting.md).

### 4. Hardware scan

Hold an NFC tag near the reader, then:

```gcode
NFC GATE=0 SCAN=1
```

The UID prints to the console. This is a raw hardware read — no Spoolman lookup, no Happy Hare update.

### 5. Full pipeline test

With a registered tag (see [Spoolman Integration](../shared/spoolman-integration.md)):

```gcode
NFC GATE=0 POLL=1
```

Expected result:
```
NFC[lane0]: one poll complete; Gate 0:  spool 42  UID 04AABBCCDD ...
```

This runs the full chain: NFC reader read → Spoolman lookup → state update → Happy Hare macro. If this works, the pipeline is complete.

---

## Step 6 — Enable Background Polling

Once a lane works end-to-end, start automatic polling:

```gcode
NFC GATE=0 READ=1
```

To start all lanes, run `READ=1` for each. Polling runs at the `poll_interval` (default: 10 seconds).

**Optional: automatic polling on startup.**
To have lanes start polling automatically after Klipper boots, set `startup_polling: 1`. The shipped `nfc_reader_hw.cfg` staggers the per-lane startup delays by 0.5 seconds so all readers don't poll simultaneously:

```ini
[nfc_gate lane0]
startup_polling:    1
startup_poll_delay: 0.0

[nfc_gate lane1]
startup_polling:    1
startup_poll_delay: 0.5

[nfc_gate lane2]
startup_polling:    1
startup_poll_delay: 1.0

[nfc_gate lane3]
startup_polling:    1
startup_poll_delay: 1.5
```

---

## Next Steps

- [Spoolman Integration](../shared/spoolman-integration.md) — register your tag UIDs
- [Commands & Macros](../shared/klipper-functions.md) — full command reference
- [Configuration Reference](../shared/configuration.md) — tune polling, logging, and timing

---

*Copyright (C) 2026 WoodWorker. Licensed under [GPL-3.0-or-later](https://www.gnu.org/licenses/gpl-3.0.html) — see [LICENSE](../../LICENSE).*

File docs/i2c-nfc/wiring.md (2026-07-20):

# NFC Reader Wiring

[README](../../Readme.md) | [Next: Install](../shared/install-uninstall.md)

This project supports PN532 and PN7160 over I2C, plus RC522 and PN5180 over
SPI. RC522 and PN5180 do not use the I2C wiring or address settings below.

| Reader | `reader_type` | Address | Bus | Best use |
|---|---|---|---|---|
| PN532 | `pn532` | `36` (`0x24`) fixed | Hardware I2C | Default, simple UID/NTAG/Bambu reader path |
| PN7160 | `pn7160` | `40-43` (`0x28-0x2B`) selectable | Hardware I2C recommended; software I2C supported | Type5/ISO15693, OpenPrintTag SLIX2, PN7160 hardware |
| RC522 | `rc522` | - | SPI | UID lookup, NTAG/Type-2, and MIFARE/Bambu reads |
| PN5180 | `pn5180` | - | SPI | ISO14443A/MIFARE and SLIX2 (ISO15693/Type-5) reads |

Use the reader-specific wiring page for the electrical details:

- [PN532 wiring](pn532-wiring.md)
- [PN7160 wiring](pn7160-wiring.md)
- [PN5180 wiring](pn5180-wiring.md) - SLB nine-wire example, power, BUSY, and RST

## Per-Lane Readers

For per-lane EMU readers, each filament gate normally gets one NFC reader wired
to that lane MCU / EBB42. Each lane has its own I2C bus, so readers on different
lane MCUs may reuse the same I2C address.

```text
lane0 EBB42  -> I2C -> NFC reader (gate 0)
lane1 EBB42  -> I2C -> NFC reader (gate 1)
lane2 EBB42  -> I2C -> NFC reader (gate 2)
```

## Shared Reader

The optional shared reader is a single NFC reader mounted inside the MMU body
and configured in `nfc_reader_shared.cfg`. It can be PN532, PN7160, RC522, or
PN5180. I2C readers need suitable SDA/SCL pins; SPI readers need a suitable
SPI bus plus chip select. The reader MCU can be the MMU MCU, a toolhead MCU, or
another MCU declared with an `[mcu ...]` section.

See [Shared Reader](../shared/shared-reader.md) for the workflow and config.

## Bus Choice

PN532 should use hardware I2C.

PN7160 supports Klipper software I2C, but hardware I2C is recommended. Software
I2C bit-bangs SDA/SCL in MCU firmware, which increases MCU load. Use software
I2C only when the selected MCU has no suitable hardware I2C bus and after bench
testing the reader.

RC522 and PN5180 use Klipper SPI. Start at `spi_speed: 500000` with a hardware
SPI bus. When software SPI is required, explicitly set `spi_speed: 100000`.
PN5180 also requires the dedicated BUSY and RST GPIO connections described in
the [PN5180 wiring guide](pn5180-wiring.md).

## Common Bring-Up Order

1. Confirm the MCU connects normally before adding the reader.
2. Wire VCC and GND.
3. Wire SDA and SCL.
4. Set the correct `reader_type` and `i2c_address`.
5. Restart Klipper.
6. Run `NFC GATE=0 INIT=1` or `NFC_SHARED INIT=1`.
7. Run `NFC GATE=0 SCAN=1` or `NFC_SHARED SCAN=1` with a tag nearby.

If basic init fails, use the reader-specific troubleshooting checks first.

---

*Copyright (C) 2026 WoodWorker. Licensed under [GPL-3.0-or-later](https://www.gnu.org/licenses/gpl-3.0.html) - see [LICENSE](../../LICENSE).*

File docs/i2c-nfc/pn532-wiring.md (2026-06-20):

# Wiring the PN532

[NFC Reader Wiring](wiring.md) | [Setup](setup.md)

For per-lane EMU readers, each filament gate gets **one PN532 wired directly to
that gate's EBB42**. There is no shared bus across the per-lane readers — each
reader lives on its own lane MCU's I2C bus.

The optional shared reader is the exception: it is a single PN532 mounted inside
the MMU body and configured separately in `nfc_reader_shared.cfg`. It still
must be wired to **some Klipper MCU's available I2C bus** — for example the MMU
MCU, a toolhead MCU, or another controller already declared with an `[mcu ...]`
section. The installer can write `i2c_mcu` / `i2c_bus` into
`nfc_reader_shared.cfg`, but it does not create or validate that physical bus;
you must pick real SDA/SCL pins supported by that MCU and wire the PN532 there.
See [Shared Reader](../shared/shared-reader.md) for that wiring/config flow.

```
lane0 EBB42  ←I2C→  PN532 (gate 0)
lane1 EBB42  ←I2C→  PN532 (gate 1)
lane2 EBB42  ←I2C→  PN532 (gate 2)
  ...
```

---

## Before You Wire Anything

> [!IMPORTANT]
> **Set the PN532 to I2C mode first, before connecting any wires.** The mode is selected by two jumpers or DIP switches on the PN532 board (labeled SEL0/SEL1, or sometimes A0/A1). If the mode is wrong, the reader will not respond on the I2C bus — and the symptoms look exactly like a wiring fault.

| Mode | SEL0 | SEL1 |
|---|:---:|:---:|
| SPI | 0 | 0 |
| **I2C ← set this** | **1** | **0** |
| UART / HSU | 0 | 1 |

Set **SEL0 = 1, SEL1 = 0**. Check your board's silkscreen — some boards number the switches in reverse, or label them differently. When in doubt, check the NXP PN532 datasheet (UM10232), Table 3.

---

## Soldering the PN532

The PN532 antenna pads are fragile — the copper ring on the top (antenna) side will lift off the board if overheated. Always solder from the back.

**Method:**

1. Insert the wire from the **back** of the board so it pokes through the hole toward the antenna side.
2. Apply the iron to the back of the board. Let solder pool up on the back pad.
3. Feed enough solder that the pool flows **through the hole** and wets the antenna-side ring — you should see a small fillet appear on the top.
4. Remove heat immediately once the solder flows through. Lingering heat is what lifts the antenna-side ring.

> [!WARNING]
> **Never apply the iron directly to the antenna-side pad.** The copper ring on the top of the board is bonded to a thin substrate and will delaminate with sustained heat. If the ring lifts, the mechanical connection is gone even if the hole still looks filled.

A proper joint: solder pool visible on the back, small filled fillet on the antenna side, wire cannot be pulled out by hand.

---

## Pin Connections

Connect each PN532 to its lane's EBB42 using these four wires:

```
EBB42 Pin       →    PN532 Module
──────────────────────────────────
PB3  (I2C SCL)  →    SCL
PB4  (I2C SDA)  →    SDA
3V3             →    VCC  (or the 3.3V pad if your board has both)
GND             →    GND
```

> [!WARNING]
> **3.3V logic only on SDA and SCL.** Some PN532 breakout boards accept 5V on the VCC pin through an onboard regulator, but the I2C signal lines must be 3.3V. The EBB42 is a 3.3V device. Never connect 5V to PB3 or PB4.

The matching Klipper config for these pins:

```ini
[nfc_gate lane0]
i2c_mcu: lane0
i2c_bus: i2c3_PB3_PB4
```

---

## I2C Address

The PN532 I2C address is **fixed at `0x24` (decimal `36`)** by the chip — it cannot be changed. The two pads/jumpers on the breakout board (SEL0/SEL1, sometimes labeled A0/A1) select the **communication protocol**, not the address. For I2C you must have SEL0=1, SEL1=0 (see the mode table above).

The address is set in `nfc_reader.cfg`:

```ini
[nfc_gate]
i2c_address: 36    ; fixed — 36 = 0x24, do not change
```

---

## Sharing the Bus with a BME280

The EBB42 typically has a BME280 temperature/humidity sensor on the same PB3/PB4 bus. This is fine — the PN532 (`0x24`) and BME280 (`0x76`) have different addresses and coexist without conflict.

> [!NOTE]
> If the BME280 worked before you added the PN532 and now fails, it is almost always a physical issue — the PN532 is in SPI or UART mode and disrupting the bus, or there is a wiring problem. See [Troubleshooting: BME280 fails after PN532 is added](troubleshooting.md#bme280-fails-after-pn532-is-added).

---

## Pull-up Resistors

I2C needs pull-up resistors on SDA and SCL. Most PN532 breakout boards include 10kΩ pull-ups, and the EBB42 also has its own. These typically work fine together.

If you add more boards (each with their own pull-ups), the parallel resistance drops and can cause marginal signaling:

- 2× 10kΩ boards in parallel → 5kΩ — fine
- 3× boards → ~3.3kΩ — usually fine
- 6+ boards → ~1.7kΩ — may be too strong

If you suspect pull-up issues: remove or bridge (disable) the PN532 board's onboard resistors and rely on the MCU's pull-ups alone.

---

## Wire Length

Keep wires short for initial bring-up — under 20cm if possible. Longer cables add capacitance that rounds signal edges, which makes marginal timing worse.

Once confirmed working, cables up to ~50cm are usually fine at 400kHz. If you see intermittent failures with longer cables, drop the I2C speed:

```ini
[nfc_gate lane0]
i2c_speed: 100000    ; 100kHz instead of 400kHz
```

---

## Bring-Up Order

Follow this sequence to avoid chasing phantom failures:

1. Confirm Happy Hare sees the lane MCU normally (no PN532 connected yet)
2. If a BME280 is fitted, confirm it reads correctly before touching anything
3. Set the PN532 DIP switches to I2C mode (SEL0=1, SEL1=0)
4. Connect VCC and GND
5. Connect SDA and SCL
6. Restart Klipper
7. Run `NFC GATE=0 INIT=1`
8. If INIT passes, run `NFC GATE=0 SCAN=1` with a tag nearby

If the BME280 breaks only after the PN532 is connected, the fault is physical — mode selection, swapped SDA/SCL, or pull-up interaction. It is not a Spoolman or Happy Hare issue.

---

*Copyright (C) 2026 WoodWorker. Licensed under [GPL-3.0-or-later](https://www.gnu.org/licenses/gpl-3.0.html) — see [LICENSE](../../LICENSE).*

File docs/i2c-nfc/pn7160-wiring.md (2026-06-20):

# Wiring the PN7160

[NFC Reader Wiring](wiring.md) | [Setup](setup.md)

PN7160 is an I2C NFC controller. In this project it can be used as a per-lane
reader or as the shared reader by setting `reader_type: pn7160`.

## Basic Wiring

The normal PN7160 connection uses four wires:

```text
MCU / EBB42       PN7160 module
--------------------------------
SCL          ->   SCL
SDA          ->   SDA
3V3          ->   VCC
GND          ->   GND
```

Use 3.3V logic on SDA/SCL. If your PN7160 board has its own power regulator,
follow the module vendor's power input notes, but keep the I2C signal voltage
compatible with the MCU.

## Optional Pins

PN7160 boards may expose extra control pins:

```ini
# ven_pin: PA8
# irq_pin: ^PC6
```

`ven_pin` controls PN7160 VEN. It is optional, but recommended when possible
because it lets Klipper hard-reset / hard-power-down the chip. Without VEN,
normal reads still work, but an abnormal Klipper stop or failed debug session
can leave the chip in a state that software cannot fully reset.

`irq_pin` is optional. When omitted, the driver uses timing-based polling.
Use IRQ only when you have a spare input pin and want to experiment with lower
latency / less polling.

## I2C Address

PN7160 supports four I2C addresses selected by hardware address pins or DIP
switches:

| Decimal | Hex |
|---:|---:|
| `40` | `0x28` |
| `41` | `0x29` |
| `42` | `0x2A` |
| `43` | `0x2B` |

The configured address must match the module's hardware address selection.
Klipper will raise a config error if `reader_type: pn7160` uses any other
address.

If each lane has its own MCU or its own I2C bus, multiple PN7160 readers can
reuse the same address. If multiple PN7160 readers share one MCU/I2C bus, each
reader must use a unique address.

## Hardware I2C vs Software I2C

Hardware I2C is recommended for PN7160.

PN7160 can run on Klipper software I2C, but software I2C consumes more MCU time
because the firmware bit-bangs SDA and SCL. That extra load matters on lane MCUs
that also handle steppers, heaters, fans, endstops, or other sensors. Use
software I2C only when the hardware layout requires it.

## Per-Lane Example

```ini
[nfc_gate lane1]
enabled:                True
reader_type:            pn7160
i2c_address:            40
mmu_gate:               1
i2c_mcu:                mmu1
i2c_bus:                i2c3_PB3_PB4
startup_poll_delay:     0.5
```

## Shared Reader Example

```ini
[nfc_gate shared]
enabled:                True
reader_type:            pn7160
i2c_address:            40
i2c_mcu:                mmu
i2c_bus:                i2c3_PB3_PB4
shared:                 true
startup_polling:        1
```

## Bring-Up Checks

1. Confirm the module address switch/pins match `i2c_address`.
2. Confirm `reader_type: pn7160` is set on that lane/shared section.
3. Confirm `i2c_mcu` matches an existing Klipper `[mcu ...]`.
4. Start with hardware I2C if possible.
5. Restart Klipper and run `NFC GATE=<n> INIT=1` or `NFC_SHARED INIT=1`.
6. Run a raw scan with a tag nearby.

If the chip gets stuck or becomes unusually warm, stop testing and power-cycle
the module. If `ven_pin` is wired, a hardware reset can recover it without
removing power.

---

*Copyright (C) 2026 WoodWorker. Licensed under [GPL-3.0-or-later](https://www.gnu.org/licenses/gpl-3.0.html) - see [LICENSE](../../LICENSE).*

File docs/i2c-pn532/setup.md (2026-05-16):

# First-Time Setup

[← Install](../shared/install-uninstall.md) | [Spoolman Setup →](../shared/spoolman-integration.md)

This guide assumes you have:
- [Wired the PN532](wiring.md) readers and set them to I2C mode
- [Installed the software](../shared/install-uninstall.md)
- Rebuilt and flashed Klipper firmware on every lane MCU

If you skipped any of those, do them first.

---

## Step 1 — Add Includes to `printer.cfg`

Add these three lines in this exact order:

```ini
[include nfc/nfc_reader.cfg]
[include nfc/nfc_macros.cfg]
[include nfc/nfc_reader_hw.cfg]
```

`nfc_reader.cfg` must come first — it defines the base `[nfc_gate]` section that each `[nfc_gate laneN]` in `nfc_reader_hw.cfg` inherits from. Reversing the order causes a Klipper config error on startup.

---

## Step 2 — Configure Spoolman

Edit `~/printer_data/config/nfc/nfc_reader.cfg`:

```ini
[nfc_gate]
spoolman_url:      auto
spoolman_rfid_key: rfid_tag
```

| Setting | Value | When to use |
|---|---|---|
| `spoolman_url: auto` | Reads URL from Moonraker | Use this when `moonraker.conf` has a `[spoolman]` section |
| `spoolman_url: http://host:7912` | Direct URL | Use when testing, or if `auto` isn't working |
| `spoolman_rfid_key: rfid_tag` | Extra field name | Must match what you create in Spoolman Settings |

See [Spoolman Integration](../shared/spoolman-integration.md) — you need to create the extra field in Spoolman and register each tag UID before spool detection will work.

---

## Step 3 — Configure Lane Hardware

Edit `~/printer_data/config/nfc/nfc_reader_hw.cfg`. The default file has four lanes; adjust to match your printer:

```ini
[nfc_gate lane0]
mmu_gate:   0
i2c_mcu:    mmu0
i2c_bus:    i2c3_PB3_PB4

[nfc_gate lane1]
mmu_gate:   1
i2c_mcu:    mmu1
i2c_bus:    i2c3_PB3_PB4
```

| Key | Required | Value |
|---|:---:|---|
| `mmu_gate` | Yes | Happy Hare gate number (0-based integer) |
| `i2c_mcu` | Yes | Klipper MCU name — must match an `[mcu laneN]` in your config |
| `i2c_bus` | Yes | I2C bus name on that MCU — use `i2c3_PB3_PB4` for PB3/PB4 on EBB42 |

> [!NOTE]
> `i2c_mcu` must exactly match the MCU name Klipper uses. These names come from Happy Hare's `mmu_hardware.cfg`, typically `lane0`, `lane1`, etc. A mismatch causes a Klipper startup error.

> [!IMPORTANT]
> **Temperature sensor I2C bus must match.** If your lane MCU has a thermistor or temperature sensor on I2C (e.g. an SHT3x), configure it on the **same hardware I2C bus** as the PN532 — the same `i2c_bus` value used in `[nfc_gate laneN]` or the base `[nfc_gate]`. Klipper's software-emulated I2C (`i2c_software_*`) is not compatible with the PN532 driver; hardware I2C is required for both devices.

All polling, timing, and logging settings are inherited from the base `[nfc_gate]` in `nfc_reader.cfg`. Override per-lane only if you need different behavior on a specific lane:

```ini
[nfc_gate lane2]
mmu_gate:   2
i2c_mcu:    mmu2
i2c_bus:    i2c3_PB3_PB4
debug:      2              ; verbose logging on this lane only
```

---

## Step 4 — Restart Klipper

```bash
sudo systemctl restart klipper
```

Watch the log for NFC startup messages:

```bash
tail -f ~/printer_data/logs/nfc_reader.log
```

Errors at this stage are almost always config typos or a missing/mismatched lane MCU name.

---

## Step 5 — Verify Each Reader

### 1. Check all gates

```gcode
NFC_STATUS
```

Expected with no tags loaded:
```
NFC gate status  (4 gates configured):
  Gate 0  [lane0]:  empty
  Gate 1  [lane1]:  empty
  Gate 2  [lane2]:  empty
  Gate 3  [lane3]:  empty
```

### 2. Watch the startup console output

When Klipper connects, each lane initialises automatically and reports to the console. Look for:

```
✅ NFC[lane0]: ready.  HH seed: spool_id=42  Startup polling is enabled; first poll in 0.0s.
```

or, if the gate was empty in Happy Hare:

```
✅ NFC[lane0]: ready.  HH reports gate empty  Run NFC GATE=0 READ=1 to start polling.
```

**The HH seed line is important.** It means NFC_Manager read Happy Hare's gate map on startup and pre-loaded the lane cache with the spool HH already knows about. The first poll will verify the physical tag matches that spool — if it does, no redundant dispatch is sent to Happy Hare. If the spool was swapped while Klipper was down, the mismatch is detected and `_NFC_SPOOL_CHANGED` fires normally.

If Happy Hare wasn't ready when the NFC init ran, the seed step is skipped. Run `NFC_HH_SYNC_CACHE` to manually re-seed all lanes from the current HH gate map.

### 3. Initialize a lane manually

```gcode
NFC GATE=0 INIT=1
```

This runs the PN532 `GetFirmwareVersion` and `SAMConfiguration` handshake. Expected output:
```
NFC[lane0]: reader OK
```

If it fails, check [Troubleshooting](troubleshooting.md).

### 4. Hardware scan

Hold an NFC tag near the reader, then:

```gcode
NFC GATE=0 SCAN=1
```

The UID prints to the console. This is a raw hardware read — no Spoolman lookup, no Happy Hare update.

### 5. Full pipeline test

With a registered tag (see [Spoolman Integration](../shared/spoolman-integration.md)):

```gcode
NFC GATE=0 POLL=1
```

Expected console output:
```
NFC gate 0: spool 42 detected (UID 04AABBCCDD). Sending to Happy Hare.
```

This runs the full chain: PN532 read → Spoolman lookup → state update → Happy Hare macro. If this works, the pipeline is complete.

---

## Step 6 — Enable Background Polling

Once a lane works end-to-end, start automatic polling:

```gcode
NFC GATE=0 READ=1
```

To start all lanes, run `READ=1` for each. Polling runs at the `poll_interval` (default: 30 seconds).

**Optional: automatic polling on startup.**
To have lanes start polling automatically after Klipper boots, set `startup_polling: 1`. The shipped `nfc_reader_hw.cfg` staggers the per-lane startup delays by 0.5 seconds so all readers don't poll simultaneously:

```ini
[nfc_gate lane0]
startup_polling:    1
startup_poll_delay: 0.0

[nfc_gate lane1]
startup_polling:    1
startup_poll_delay: 0.5

[nfc_gate lane2]
startup_polling:    1
startup_poll_delay: 1.0

[nfc_gate lane3]
startup_polling:    1
startup_poll_delay: 1.5
```

---

## Next Steps

- [Spoolman Integration](../shared/spoolman-integration.md) — register your tag UIDs
- [Commands & Macros](../shared/klipper-functions.md) — full command reference
- [Configuration Reference](../shared/configuration.md) — tune polling, logging, and timing

---

*Copyright (C) 2026 WoodWorker. Licensed under [GPL-3.0-or-later](https://www.gnu.org/licenses/gpl-3.0.html) — see [LICENSE](../../LICENSE).*

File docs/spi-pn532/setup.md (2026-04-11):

# SPI / PN532 — Setup & Deployment

[← Back to Index](../../Readme.md)

---

## Hardware Path: SPI / PN532

Use this path when you have a **dedicated Raspberry Pi Pico** connected to the CAN bus
with PN532 NFC readers wired to its SPI1 bus.

The PN532 handles the full ISO14443A stack in hardware — one `InListPassiveTarget`
command returns the tag UID directly with no manual REQA/ANTICOLL/SELECT sequence
required. This keeps CAN bus traffic lower than the RC522 path.

---

## Prerequisites

- Klipper installed on a Raspberry Pi (klippy running)
- CAN bus working (e.g. with an EBB36/42 toolhead board already on the bus)
- Raspberry Pi Pico + SN65HVD230 CAN transceiver, wired per [wiring.md](wiring.md)
- PN532 modules wired to Pico SPI1 per [wiring.md](wiring.md)
- Each PN532 set to **SPI mode** via its onboard DIP switch or solder jumper

---

## Step 1 — Install from Git

Clone the repository using sparse checkout so the `tests/` directory (development
only) is not downloaded to the printer. Run the install script, which creates symlinks
from the repo into Klipper's extras directory — future `git pull` updates take effect
after a Klipper restart, with no re-install needed.

```bash
cd ~
git clone --filter=blob:none --sparse YOUR_REPO_URL_HERE emu-nfc-reader
cd ~/emu-nfc-reader
git sparse-checkout set klippy config docs
cd ~
bash ~/emu-nfc-reader/install.sh
```

Verify the symlinks were created:

```bash
ls -la ~/klipper/klippy/extras/nfc_gates
ls -la ~/klipper/klippy/extras/nfc_gate.py
```

Both should point back into `~/emu-nfc-reader/`.

---

## Step 2 — Build Klipper MCU Firmware for the Pico

```bash
cd ~/klipper
make menuconfig
```

Select these options:

| Setting | Value |
|---|---|
| Micro-controller | Raspberry Pi RP2040 |
| Communication interface | CAN bus |
| CAN TX GPIO | 4 |
| CAN RX GPIO | 5 |
| CAN bus speed | 1000000 (1 Mbit/s) |

Then build:

```bash
make clean && make
```

Output firmware: `out/klipper.uf2`

> SPI pin assignments are **not** set in `make menuconfig`. They are configured at
> runtime by Klipper's `MCU_SPI` interface using the `cs_pin` and `spi_bus` keys
> in `pn532_spi.cfg`.

---

## Step 3 — Flash the Pico

Hold **BOOTSEL** and connect the Pico to the Pi via USB:

```bash
cp out/klipper.uf2 /media/$USER/RPI-RP2/
```

The Pico reboots automatically into Klipper MCU firmware and appears on the CAN bus.

If the Pico is already on CAN running an older Klipper build:

```bash
python3 ~/klipper/scripts/flash_can.py -u <current_uuid> -f out/klipper.uf2
```

---

## Step 4 — Find the Pico CAN UUID

```bash
~/klippy-env/bin/python ~/klipper/scripts/canbus_query.py can0
```

Expected output:

```
Found canbus_uuid=aabbccddeeff, Application: Klipper
```

Note the UUID — you will paste it into the config in the next step.

---

## Step 5 — Configure printer.cfg

`install.sh` already copied all config files to `~/printer_data/config/NFC/`.
Add these includes to `printer.cfg` **in this order**:

```ini
[include NFC/nfc_vars.cfg]
[include NFC/nfc_macros.cfg]
[include NFC/pn532_spi.cfg]
```

- **`NFC/nfc_vars.cfg`** is the one file you edit — set your Spoolman URL, poll interval, and debug level here. It must be included before the hardware config.
- **`NFC/nfc_macros.cfg`** contains the Happy Hare integration macros and is shared between all hardware paths.
- **`NFC/pn532_spi.cfg`** contains only hardware-specific settings.

Edit these files:

| File | Key | What to do |
|---|---|---|
| `NFC/nfc_vars.cfg` | `spoolman_url` | Set to your Spoolman instance URL |
| `NFC/pn532_spi.cfg` | `canbus_uuid` | Replace `YOUR_UUID_HERE` with the UUID from Step 4 |
| `NFC/pn532_spi.cfg` | `extra_cs_pins` | Remove entries for gates you don't have wired |

---

## Step 6 — Set Up Moonraker Auto-Update

Add this section to `~/printer_data/config/moonraker.conf`:

```ini
[update_manager emu_nfc_reader]
type: git_repo
path: ~/emu-nfc-reader
origin: YOUR_REPO_URL_HERE
primary_branch: main
managed_services: klipper
install_script: install.sh
```

Restart Moonraker:

```bash
sudo systemctl restart moonraker
```

Updates will now appear in the Mainsail / Fluidd update panel alongside Klipper itself.

---

## Step 7 — Restart Klipper and Verify

```bash
sudo systemctl restart klipper
```

Check the NFC log for successful initialisation:

```bash
tail -f ~/printer_data/logs/nfc_reader.log
```

Expected output:

```
nfc_gates: connected to MCU 'nfc_pico', initialising 5 gates (poll=30s, absent_threshold=3)
init: gate 0 (PN532) SAMConfiguration OK
init: gate 1 (PN532) SAMConfiguration OK
init: gate 2 (PN532) SAMConfiguration OK
init: gate 3 (PN532) SAMConfiguration OK
init: gate 4 (PN532) SAMConfiguration OK
nfc_gates: 5/5 readers initialised
nfc_gates: polling thread started
```

If any reader fails — see [Troubleshooting](troubleshooting.md).

---

## Step 8 — Test Tag Detection

From the Klipper console (Mainsail / Fluidd terminal):

```
NFC_GATE_STATUS
```

All gates should show `empty` before any tags are placed.

Place an NFC spool tag on Gate 0. Within one poll cycle (30 s default):

```
NFC gate 0: spool 1042 detected (UID A3F200CC)
```

---

## Updating the Module

With Moonraker configured (Step 6), updates appear in the update panel automatically.

To update manually:

```bash
cd ~/emu-nfc-reader
git pull
bash install.sh
sudo systemctl restart klipper
```

---

## Uninstalling

### 1 — Remove the Klipper extra symlinks

```bash
rm ~/klipper/klippy/extras/nfc_gate.py
rm -rf ~/klipper/klippy/extras/nfc_gates
```

### 2 — Remove the printer config files

```bash
rm -rf ~/printer_data/config/NFC
```

Remove the three `[include NFC/...]` lines from `printer.cfg`.

### 3 — Remove the Moonraker update manager entry

Delete the `[update_manager emu_nfc_reader]` block from `moonraker.conf`, then restart Moonraker:

```bash
sudo systemctl restart moonraker
```

### 4 — Remove the repo clone

```bash
rm -rf ~/emu-nfc-reader
```

### 5 — Restart Klipper

```bash
sudo systemctl restart klipper
```

---

**Next:** [Wiring Diagram →](wiring.md)

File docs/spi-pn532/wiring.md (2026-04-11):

# SPI / PN532 — Wiring Diagram & Pin Reference

[← Back to SPI/PN532 Setup](setup.md) | [← Back to Index](../../Readme.md)

---

## Overview

One **Raspberry Pi Pico** connects to the CAN bus and hosts up to 5 PN532 readers
on its hardware SPI1 bus. All readers share SCK, MOSI, and MISO.
Each reader has its own CS (chip-select) GPIO.

The PN532 uses **SPI mode 0** (CPOL=0, CPHA=0) with **LSB-first** byte order.
The driver handles bit-reversal in software — no special firmware configuration required.

---

## PN532 Mode Selection

Before wiring, set each PN532 module to **SPI mode**. Most breakout boards have a
DIP switch or solder jumpers to select the interface:

| SEL0 | SEL1 | Mode |
|---|---|---|
| L | L | **SPI** ← use this |
| H | L | I2C |
| L | H | HSU (UART) |

> Consult your module's datasheet if the switches are labelled differently.
> The SparkFun and Adafruit PN532 boards use the SEL0/SEL1 convention above.

---

## CAN Bus Transceiver

The Pico cannot drive CAN bus directly. A 3.3V CAN transceiver module
(e.g. SN65HVD230) is required between the Pico GPIO and the CAN bus differential pair.

> Use a **3.3V** transceiver. Do **not** use a 5V module (e.g. MCP2551) —
> the Pico's GPIO is not 5V tolerant.

> Tie the transceiver's RS / slope-control pin to GND for high-speed mode
> (required at 1 Mbit/s).

> The CAN bus must be terminated with 120 Ω between CANH and CANL at each physical
> end of the bus.

```
Raspberry Pi Pico          SN65HVD230
┌─────────────┐            ┌──────────────────┐
│  GP4 (TX) ──┼────────────┼─► TXD            │
│  GP5 (RX) ──┼────────────┼─◄ RXD            │
│  3V3 OUT  ──┼────────────┼─► VCC (3.3V)     │
│  GND      ──┼────────────┼─► GND            │
└─────────────┘            │   CANH ──────────┼──► CAN bus (CANH)
                           │   CANL ──────────┼──► CAN bus (CANL)
                           └──────────────────┘
```

---

## Full Wiring Diagram (5-gate example)

```
Raspberry Pi Pico
┌──────────────────────────────────────────┐
│                                          │
│  GP4 (CAN TX) ────────────────────────── TXD  SN65HVD230
│  GP5 (CAN RX) ────────────────────────── RXD  SN65HVD230
│                                          │
│  GP0  ──────────────────────────────── NSS  PN532 Gate 0
│  GP1  ──────────────────────────────── NSS  PN532 Gate 1
│  GP2  ──────────────────────────────── NSS  PN532 Gate 2
│  GP3  ──────────────────────────────── NSS  PN532 Gate 3
│  GP6  ──────────────────────────────── NSS  PN532 Gate 4
│                                          │
│  GP8  (SPI1 MISO) ─────────────┬──────── MISO PN532 Gate 0
│                                ├──────── MISO PN532 Gate 1
│                                ├──────── MISO PN532 Gate 2
│                                ├──────── MISO PN532 Gate 3
│                                └──────── MISO PN532 Gate 4
│                                          │
│  GP10 (SPI1 SCK)  ─────────────┬──────── SCK  PN532 Gate 0
│                                ├──────── SCK  PN532 Gate 1
│                                ├──────── SCK  PN532 Gate 2
│                                ├──────── SCK  PN532 Gate 3
│                                └──────── SCK  PN532 Gate 4
│                                          │
│  GP11 (SPI1 MOSI) ─────────────┬──────── MOSI PN532 Gate 0
│                                ├──────── MOSI PN532 Gate 1
│                                ├──────── MOSI PN532 Gate 2
│                                ├──────── MOSI PN532 Gate 3
│                                └──────── MOSI PN532 Gate 4
│                                          │
│  3V3 OUT ──────────────────────┬──────── VCC  PN532 Gate 0
│                       (also ──►│ VCC SN65HVD230)
│                                ├──────── VCC  PN532 Gate 1
│                                ├──────── VCC  PN532 Gate 2
│                                ├──────── VCC  PN532 Gate 3
│                                └──────── VCC  PN532 Gate 4
│                                          │
│  GND ──────────────────────────┬──────── GND  PN532 Gate 0
│                       (also ──►│ GND SN65HVD230)
│                                ├──────── GND  PN532 Gate 1
│                                ├──────── GND  PN532 Gate 2
│                                ├──────── GND  PN532 Gate 3
│                                └──────── GND  PN532 Gate 4
└──────────────────────────────────────────┘
```

---

## Pin Reference Table

| Pico GPIO | Function | Connected To | Notes |
|---|---|---|---|
| GP0 | PN532 CS (Gate 0) | PN532 Gate 0 NSS | Chip select — active low |
| GP1 | PN532 CS (Gate 1) | PN532 Gate 1 NSS | Chip select — active low |
| GP2 | PN532 CS (Gate 2) | PN532 Gate 2 NSS | Chip select — active low |
| GP3 | PN532 CS (Gate 3) | PN532 Gate 3 NSS | Chip select — active low |
| **GP4** | **CAN TX** | **SN65HVD230 TXD** | **CAN bus transmit** |
| **GP5** | **CAN RX** | **SN65HVD230 RXD** | **CAN bus receive** |
| GP6 | PN532 CS (Gate 4) | PN532 Gate 4 NSS | Chip select — active low |
| GP8 | SPI1 MISO | All PN532 MISO | Shared data in |
| GP10 | SPI1 SCK | All PN532 SCK | Shared clock — 1 MHz |
| GP11 | SPI1 MOSI | All PN532 MOSI | Shared data out |
| 3V3 OUT | — | PN532 VCC + transceiver VCC | 3.3V rail — do not use 5V |
| GND | — | PN532 GND + transceiver GND | Common ground |

---

## PN532 Module Pinout

| PN532 Pin | Function | Connect to |
|---|---|---|
| VCC | Power | Pico 3V3 OUT |
| GND | Ground | Pico GND |
| NSS | SPI Chip Select | Unique Pico GPIO per gate (GP0–GP6) |
| SCK | SPI Clock | Pico GP10 (shared) |
| MOSI | SPI data in to PN532 | Pico GP11 (shared) |
| MISO | SPI data out from PN532 | Pico GP8 (shared) |

> **Voltage:** PN532 modules run at 3.3V. The Pico's GPIO is 3.3V native — no level
> shifters required. Do **not** connect PN532 VCC to the Pico's VBUS (5V) pin.

> **No RST pin needed:** The PN532 is reset via the `GetFirmwareVersion` wake sequence
> in software. Leave the RST pin unconnected or tie it to 3.3V.

---

## Notes on Shared Lines

SCK, MOSI, MISO, VCC, and GND are shared across all PN532 modules.
Only the NSS (CS) line is unique per module — daisy-chain the shared lines across
all boards and run individual wires only for NSS.

**RF isolation:** All PN532 antenna coils are powered simultaneously. The CS pin
provides software isolation only — only one reader is selected on SPI at a time.
For physical RF isolation between adjacent gates, maintain at least **3 cm** separation
between antenna coils, or use ferrite backing behind each antenna.

**LSB-first note:** The PN532 SPI interface transfers data LSB first, which is the
opposite of most SPI devices. The driver handles this automatically via software
bit-reversal — no hardware or firmware configuration is required on the Pico.

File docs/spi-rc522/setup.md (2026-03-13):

# SPI / RC522 — Setup & Deployment

[← Back to Index](../../Readme.md)

---

## Hardware Path: SPI / RC522

Use this path when you have a **dedicated Raspberry Pi Pico** connected to the CAN bus
with RC522 NFC readers wired to its SPI1 bus.

**You do NOT need this path** if your EMU gates are wired to EBB42 lane boards with PN532
readers — use the [I2C / PN532 path](../i2c-pn532/setup.md) instead.

---

## Prerequisites

- Klipper installed on a Raspberry Pi (klippy running)
- CAN bus working (e.g. with an EBB36/42 toolhead board already on the bus)
- Raspberry Pi Pico + SN65HVD230 CAN transceiver, wired per [wiring.md](wiring.md)
- RC522 modules wired to Pico SPI1 per [wiring.md](wiring.md)

---

## Step 1 — Install from Git

Clone the repository using sparse checkout so the `tests/` directory (development
only) is not downloaded to the printer. Run the install script, which creates symlinks
from the repo into Klipper's extras directory — future `git pull` updates take effect
after a Klipper restart, with no re-install needed.

```bash
cd ~
git clone --filter=blob:none --sparse YOUR_REPO_URL_HERE emu-nfc-reader
cd ~/emu-nfc-reader
git sparse-checkout set klippy config docs
cd ~
bash ~/emu-nfc-reader/install.sh
```

Verify the symlinks were created:

```bash
ls -la ~/klipper/klippy/extras/nfc_gates
ls -la ~/klipper/klippy/extras/nfc_gate.py
```

Both should point back into `~/emu-nfc-reader/`.

---

## Step 2 — Build Klipper MCU Firmware for the Pico

```bash
cd ~/klipper
make menuconfig
```

Select these options:

| Setting | Value |
|---|---|
| Micro-controller | Raspberry Pi RP2040 |
| Communication interface | CAN bus |
| CAN TX GPIO | 4 |
| CAN RX GPIO | 5 |
| CAN bus speed | 1000000 (1 Mbit/s) |

Then build:

```bash
make clean && make
```

Output firmware: `out/klipper.uf2`

> SPI pin assignments are **not** set in `make menuconfig`. They are configured at
> runtime by Klipper's `MCU_SPI` interface using the `cs_pin` and `spi_bus` keys
> in `nfc_gates_spi_rc522.cfg`.

---

## Step 3 — Flash the Pico

Hold **BOOTSEL** and connect the Pico to the Pi via USB:

```bash
cp out/klipper.uf2 /media/$USER/RPI-RP2/
```

The Pico reboots automatically into Klipper MCU firmware and appears on the CAN bus.

If the Pico is already on CAN running an older Klipper build:

```bash
python3 ~/klipper/scripts/flash_can.py -u <current_uuid> -f out/klipper.uf2
```

---

## Step 4 — Find the Pico CAN UUID

```bash
~/klippy-env/bin/python ~/klipper/scripts/canbus_query.py can0
```

Expected output:

```
Found canbus_uuid=aabbccddeeff, Application: Klipper
```

Note the UUID — you will paste it into the config in the next step.

---

## Step 5 — Configure printer.cfg

Copy all three config files to your Klipper config directory:

```bash
cp ~/emu-nfc-reader/config/nfc_macros.cfg           ~/printer_data/config/
cp ~/emu-nfc-reader/config/nfc_vars.cfg              ~/printer_data/config/
cp ~/emu-nfc-reader/config/nfc_gates_spi_rc522.cfg  ~/printer_data/config/
```

Add all three includes to `printer.cfg` **in this order**:

```ini
[include nfc_vars.cfg]
[include nfc_macros.cfg]
[include nfc_gates_spi_rc522.cfg]
```

- **`nfc_vars.cfg`** is the one file you edit for your installation — set your Spoolman URL, poll interval, and debug level here. It must be included before the hardware config.
- **`nfc_macros.cfg`** contains the Happy Hare integration macros and is shared between both hardware paths.
- **`nfc_gates_spi_rc522.cfg`** contains only hardware-specific settings.

Edit `~/printer_data/config/nfc_vars.cfg` and `~/printer_data/config/nfc_gates_spi_rc522.cfg`:

| File | Key | What to do |
|---|---|---|
| `nfc_vars.cfg` | `spoolman_url` | Set to your Spoolman instance URL |
| `nfc_gates_spi_rc522.cfg` | `canbus_uuid` | Replace `YOUR_UUID_HERE` with the UUID from Step 4 |
| `nfc_gates_spi_rc522.cfg` | `extra_cs_pins` | Remove entries for gates you don't have wired |

---

## Step 6 — Set Up Moonraker Auto-Update

Add this section to `~/printer_data/config/moonraker.conf`:

```ini
[update_manager emu_nfc_reader]
type: git_repo
path: ~/emu-nfc-reader
origin: YOUR_REPO_URL_HERE
primary_branch: main
managed_services: klipper
install_script: install.sh
```

Restart Moonraker:

```bash
sudo systemctl restart moonraker
```

Updates will now appear in the Mainsail / Fluidd update panel alongside Klipper itself.
Moonraker runs `install.sh` after each update to refresh the symlinks, then restarts Klipper.

---

## Step 7 — Restart Klipper and Verify

```bash
sudo systemctl restart klipper
```

Check the log for successful initialisation:

```bash
tail -f ~/printer_data/logs/klippy.log | grep nfc_gates
```

Expected output:

```
nfc_gates: connected to MCU 'nfc_pico', initialising 5 gates (poll=30s, absent_threshold=3)
nfc_gates: gate 0 RC522 init OK (TxControl=0x83)
nfc_gates: gate 1 RC522 init OK (TxControl=0x83)
nfc_gates: gate 2 RC522 init OK (TxControl=0x83)
nfc_gates: gate 3 RC522 init OK (TxControl=0x83)
nfc_gates: gate 4 RC522 init OK (TxControl=0x83)
nfc_gates: 5/5 readers initialised
nfc_gates: polling thread started
```

If any reader fails: `nfc_gates: gate N reader did not respond after init (check wiring)`
— see [Troubleshooting](troubleshooting.md).

---

## Step 8 — Test Tag Detection

From the Klipper console (Mainsail / Fluidd terminal):

```
NFC_GATE_STATUS
```

All gates should show `empty` before any tags are placed.

Place an NFC spool tag on Gate 0. Within one poll cycle (30 s, or 5 s if you reduced it):

```
NFC gate 0: spool 1042 detected (UID A3F200CC)
```

Remove the tag. After 3 missed polls (90 s at the default 30 s interval):

```
NFC gate 0: spool removed
```

If you see `has no spool ID`, the tag has not been written yet.
See [Writing Spool IDs to NFC Tags](../shared/tag-writing.md).

---

## Updating the Module

With Moonraker configured (Step 6), updates appear in the update panel automatically.

To update manually:

```bash
cd ~/emu-nfc-reader
git pull
bash install.sh
sudo systemctl restart klipper
```

---

**Next:** [Wiring Diagram →](wiring.md) | [Troubleshooting →](troubleshooting.md)

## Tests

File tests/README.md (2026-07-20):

# Tests

Two independent suites, run together via `bash tests/run_tests.sh`:

- **`tests/bash/`** — unit tests for `install.sh` / `uninstall.sh` helper
  functions. No external dependencies (no bats) — a small harness in
  `tests/bash/lib/harness.sh` provides `assert_*` helpers and runs each
  `test_*` function in an isolated sandbox dir.

  `install.sh` is a top-to-bottom script with no `main` guard, so a test
  file extracts just the function(s) it needs via
  `tests/bash/lib/extract_functions.sh` rather than sourcing the whole
  script (which would run the interactive installer). If a function is
  renamed, extraction fails loudly instead of silently testing nothing.

  Run directly: `bash tests/bash/run_all.sh`
  Run one file: `bash tests/bash/test_install_managed_macros.sh`

- **`tests/python/`** — pytest unit tests for `klippy/extras/nfc_gates`.
  Modules that only need pure logic (e.g. `gate_state.py`) are tested with
  no mocking. Modules that talk to Klipper (e.g. `klipper_interface.py`)
  are tested against small fakes in `tests/python/fakes.py`
  (`FakePrinter`/`FakeReactor`/`FakeGCode`) rather than a real Klipper
  install.

  `tests/python/conftest.py` also works around an import-time side effect:
  `nfc_gates/log.py` builds its logger at import time by locating
  `klippy.log`'s directory through the root logger, falling back to
  `~/printer_data/logs` — which doesn't exist off-printer. conftest attaches
  a stub `FileHandler` pointing at a temp dir to the root logger *before*
  any `nfc_gates` module is imported, so that fallback never triggers.

  Setup: `pip install -r tests/python/requirements-dev.txt`
  Run: `pytest tests/python`

## What's covered so far

This is a scaffold, not full coverage. Included as worked examples of each
pattern:

- `install_managed_macros` (the read-only `nfc_macros.cfg` symlink logic)
  and `merge_config` (the non-destructive merge for user-owned config
  files) in `install.sh`.
- `GateState` (per-gate debounce state machine) and `KlipperInterface`
  (event → G-code macro dispatch) in `klippy/extras/nfc_gates/`.

Extending either suite means adding a new `test_*.sh` / `test_*.py` file
next to the existing ones — no registration step needed, both runners
discover files by naming convention.

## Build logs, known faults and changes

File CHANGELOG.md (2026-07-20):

# Changelog

All notable changes to the EMU NFC Gate Reader are documented here.
Format follows [Keep a Changelog](https://keepachangelog.com/en/1.1.0/).

**Legend:** ✨ Added · 🐛 Fixed · ♻️ Changed · 📝 Docs · ✅ Verified · 💡 Note

---

## [Unreleased]

### One-Time Installer and Moonraker Web Updates

- ♻️ **The interactive installer now runs once** — an existing installation
  exits without revisiting setup or rewriting user configuration.
- ✨ **Added `-r` / `--repair`** — repair restores installer-owned Python and
  macro links, ordered printer includes, the Moonraker updater, and the install
  state marker while preserving NFC reader and hardware settings.
- ✨ **Added `-c` / `--reconfigure`** — users can intentionally rerun the setup
  wizard to change reader choices without manually rebuilding the config files;
  the complete NFC configuration is backed up before changes are applied.
- ♻️ **Normal updates now use Moonraker's web interface** — the deprecated
  `install_script` updater hook was removed; Moonraker updates the checkout and
  restarts Klipper directly.
- ♻️ **`nfc_macros.cfg` is read-only** — the protected Happy Hare interface is
  linked to the shipped file and existing local copies are backed up once.

## [1.3.1] - 07/17/2026 - WoodWorker

### Scan-Jog Rewind LED Release Cleanup

- 🐛 **Fixed lane LEDs sticking in the rewind effect after scan-jog** — NFC now
  releases the temporary rewind LED for the active gate immediately after the
  fast rewind-to-buffer move completes, before handing filament parking back
  to Happy Hare via `_MMU_STEP_UNLOAD_GATE`.
- ♻️ **Per-gate LED release is now explicit** — Happy Hare v3 release now sends
  `MMU_SET_LED GATE=<gate> EXIT_EFFECT=gate_status FADETIME=0` before the
  quiet gate-map refresh, so the lane returns to Happy Hare's normal
  gate-status display instead of relying on a global `MMU_GATE_MAP QUIET=1`
  repaint to clear the temporary effect.
- 🐛 **Prevented the cleanup release from causing a second LED blink** — scan
  jog tracks whether the rewind LED was already released for the current
  cycle. The end-of-scan cleanup now retries only if the earlier release
  failed, avoiding a sloppy-looking second repaint in the normal path.
- ♻️ **Happy Hare v4 release remains direct-effect based** — per-gate release
  now removes only the tracked NFC lane effect for that gate, while full
  release still stops every tracked NFC direct effect and refreshes the gate
  map.

## [1.3.0] - 07/15/2026 - WoodWorker

### NFC_DOCTOR Virtual Endstop Visibility + ENDSTOP=ADD Insertion Fix

- ✨ **Per-lane virtual endstop status in `NFC_DOCTOR`** — each enabled gate's
  line now ends with `virtual_endstop: Loaded` or `Unloaded`
  (`_nfc_endstop_status_text()` in `nfc_manager.py`), reading directly off
  `printer.lookup_object("mmu_nfc_endstop laneN")` so a missing or
  not-yet-restarted endstop is visible on the same line as the gate itself,
  not just in the aggregate summary below.
- 🐛 **Fixed `NFC_DOCTOR GATE=<#> ENDSTOP=ADD` inserting in the wrong spot** —
  `_insert_nfc_endstop_after_lane()` searched only for the next `[section]`
  header as a stopping point, so it skipped over the next lane's comment
  banner (e.g. `# ===== LANE 2 =====`) and dropped the new
  `[mmu_nfc_endstop laneN]` block after the banner instead of before it. It
  now also stops at the first blank line, matching where the block sits in
  the shipped `nfc_reader_hw.cfg` template.
- ♻️ **Removed the Happy Hare version compatibility line from `NFC_DOCTOR`** —
  that check (scan-jog `action=idle`/`action=checking` support) belongs to
  scan-jog's own gating logic, not doctor's config/reader/Spoolman scope.
- 📝 **`NFC_HELP` updated** to mention virtual endstop checking under the
  `NFC_DOCTOR` entry.

## [1.2.0] - 07/11/2026 - WoodWorker

### TigerTag Left-Neighbor Interference Detection

Left-neighbor interference detection (shifting an adjacent gate's spool out
of the reader field when its tag is misread as the current gate's) only
worked for Bambu tags, since Bambu is the only supported format that ships
two physical tags per spool — the only case where a plain UID comparison
against the neighbor's cache can't tell "same spool, other side's tag" apart
from "genuinely different spool."

- ✨ **Twin Tag ID extraction** — `_try_tigertag()` (`vendor/rfid_tag_parser.py`)
  now reads a 4-byte big-endian field at offset `+32` (page `0x0C`), written
  identically to both physical tags when a spool's left/right sides are
  programmed together. Stored as `info["tigertag_twin_tag_id"]`.
- ✨ **Wired into `spool_identity`** as `"tigertag_%d" % twin_tag_id`, the same
  field Bambu populates from `tray_uid` as `"bambu_%s" % tray_uid`. No
  changes needed in `scan_jog.py`: the existing `current_spool_identity()` /
  `spool_identity_for_gate()` / `is_left_neighbor_spool_identity_match()`
  chain compares `spool_identity` generically, with no awareness of which
  parser produced it — so TigerTag spools with matching Twin Tag IDs on
  adjacent gates now get the same automatic clearance jog Bambu spools
  already had.
- 💡 **No new tag reads required** — the twin tag ID falls within the 64 bytes
  (`tag_max_pages: 16` default) already fetched per read. `_try_tigertag()`
  previously stopped parsing at offset 31 even though the bytes past it were
  already present in its `raw` buffer.
- ✅ **Confirmed, not inferred** — TigerTag's own published RFID guide documents
  a genuine two-tags-per-spool design with this field as the same-spool
  pairing key.

### QIDI Box / Creality CFS Default-Key MIFARE Fallback Enabled

Rich reads for any non-Bambu MIFARE Classic tag (QIDI Box, Creality CFS)
never actually worked: `read_current_tag()` (`tag_handler.py`) only ever
tried Bambu's own HKDF-derived keys, and the intended default-key retry for
everyone else existed in the file but was commented out pending hardware
confirmation.

- ✅ **QIDI Box key confirmed** — the plain MIFARE Classic factory default Key
  A, `FF FF FF FF FF FF`. Not a secret; sourced from the community
  `TinkerBarn/BoxRFID-Touch` project (same PN532 chip family this project
  already uses), which authenticates block 4 with this exact key before
  reading/writing material/color/manufacturer codes. Creality CFS's real key
  turned out to be neither the default key nor a simple custom key — see
  "Creality CFS/K1/K2 AES Tag Support" below.
- 🐛 **QIDI material lookup aligned to QIDI's RFID guide** — corrected the
  QIDI material code table used by `_try_qidi_box()` so codes 42-50 match
  the official wiki values (`PETG-CF`, `PETG-GF`, `PPS-CF`, `TPU`, etc.)
  and wiki-reserved/blank codes remain reported as `Unknown(n)`. Parsed QIDI
  metadata now also keeps the raw `material_code`, `color_code`, and
  `manufacturer_code` for debugging real tags.
- ✨ **Creality spool identity added for left-neighbor checks** — `_try_creality_tag()`
  now hashes the parsed structured payload fields
  `vendor_id:date_code:batch:filament_id:color:length:serial` into a compact
  decimal value and exposes it as `spool_identity = "creality_<digits>"`.
  The UID is deliberately not part of this value because `spool_identity`
  represents same-spool identity, not same-chip identity. The readable seed
  and numeric value are kept in metadata/debug output as
  `creality_identity_seed` and `creality_identity_numeric`.
- 📝 **Documented same-spool identity support** — README and shared docs now
  describe the Bambu-style `spool_identity` model for Bambu, TigerTag, and
  Creality rich tags, including the Creality payload fields used and the
  fact that Creality support has been tested against real spool tags.
- 🐛 **Scan-jog now preserves stashed spool identity** — the continuous-scan
  fast path that reuses a previously resolved UID now carries the previous
  `spool_identity` along with the spool id, and level-3 logs show both the
  current lane identity and the left lane identity used for interference
  decisions. When the pending UID matches the stashed UID, scan-jog now tries
  Spoolman UID lookup before accepting the stashed spool id; if the lookup
  has no cached `spool_identity`, it forces the rich tag parse so manufacturer
  `spool_identity` is populated before any auto-create path.
- 🐛 **Spoolman UID matches no longer suppress scan-mode identity parsing** —
  during scan-jog, an early Spoolman UID match still supplies the spool id,
  but structured tag reading continues so Bambu/Creality/TigerTag
  `spool_identity` is cached on the gate for left-neighbor comparisons.
- 🐛 **Spoolman-resolved NTAGs no longer burn decode retries** — after the
  initial scan-mode identity parsing change, any `tag_parsing: True` read
  that resolved through Spoolman could still be forced down the rich-read
  path when `spool_identity` was missing. That caused ordinary NTAG /
  UID-registered spools to run the 5-position decode retry loop even though
  the UID had already resolved to a valid Spoolman spool. Scan-jog and the
  early UID lookup now force rich parsing only when the resolved Spoolman
  spool matches the left neighbor's cached spool, which is the case where a
  manufacturer `spool_identity` is needed to confirm left-neighbor
  interference. Clean Spoolman UID hits for other spools now resolve
  immediately.
- 🐛 **Manufacturer identity is checked before auto-create** — after rich tag
  metadata is parsed and Spoolman UID lookup misses, scan mode compares the
  current tag's `spool_identity` against the left gate before allowing
  metadata-direct or auto-created spool resolution to continue.
- 🐛 **Left-neighbor clearance resumes with a fresh lane scan** — after a
  left-neighbor interference hit, scan-jog now clears stale UID/continuous
  hit-window state and resets the current lane's scan-local state as if a new
  `JOG_SCAN=1` had been issued after shifting the left lane, instead of
  reprocessing the same false read.
- 🐛 **Default-key retry enabled and restructured** in `read_current_tag()`.
  Previously it only fired if Bambu key *derivation* succeeded and then
  every sector's *authentication* failed — meaning it silently never ran at
  all for anyone without `pycryptodome` installed, since derivation itself
  would fail first and return before the retry was ever reached. The trigger
  is now "Bambu didn't produce a usable read, for any reason" (derivation
  failure or all-sectors-auth-failure), so QIDI/Creality reads work
  correctly even with `pycryptodome` absent — appropriate, since the
  default-key path needs no cryptography library at all.
- 💡 **No changes needed in `parse_tag()`** — the MIFARE block-dict →
  flat-buffer conversion that feeds `_try_qidi_box()`/`_try_creality_cfs()`
  already existed and was already correct; the only missing piece was ever
  reaching it with a second, correct key.
- 💡 **`bambu_reads: True` stays the single gate** for all authenticated MIFARE
  Classic attempts (Bambu's own keys and the default-key fallback alike) —
  left unrenamed despite now covering more than Bambu, since renaming a
  public config key is a breaking change out of scope here. `pycryptodome`
  remains required only for Bambu's own reads.
- 📝 **Documented** the confirmed QIDI key value and the (at the time)
  unconfirmed Creality status in `docs/shared/configuration.md`,
  `docs/shared/spoolman-integration.md`, and `Readme.md`.

### Creality CFS/K1/K2 AES Tag Support

The default-key retry above never worked for genuine Creality tags: unlike
QIDI Box, Creality's tag encoder derives a per-UID MIFARE Key B and encrypts
the payload itself, so both Bambu's Key A and the plain default key fail on
sector 1. This closes out the "unconfirmed" status from the previous entry.

**MIFARE Classic key attempts, in order** (`read_current_tag()` in
`tag_handler.py`), each only firing when the previous one authenticated
nothing:

| Order | Scheme | Sectors | Key type | Extra dependency |
|---|---|---|---|---|
| 1 | Bambu HKDF-derived | 0-4 | Key A | `pycryptodome` |
| 2 | MIFARE factory default (QIDI Box) | 0-4 | Key A (`FF FF FF FF FF FF`) | none |
| 3 | Creality UID-derived | 1 only | Key B | `pycryptodome` |

Each retry re-selects the same UID via the new `_retarget_same_uid()` helper
before authenticating, since a completed `mifare_read_authenticated_blocks()`
call always releases the target.

- ✨ **Key derivation and decryption** — added `_creality_derive_key_b()`
  (`vendor/rfid_tag_parser.py`): the sector-1 MIFARE Key B is
  `AES-128-ECB(AES_KEY_GEN, uid repeated to 16 bytes)[:6]`.
  `_creality_decrypt_tag_data()` then decrypts the 48-byte ASCII payload
  stored across blocks 4-6 with a second static key, `AES_KEY_CIPHER`. Both
  keys and the derivation procedure are community-sourced from a Creality
  RFID encryption helper script that mirrors the JavaScript implementation
  used by Creality's own tag-writer tooling; no code was copied, only the
  two key constants and the encrypt/decrypt procedure they document.
  ✅ Verified against the reference script's own key-generation and
  encrypt/decrypt output before wiring in. Hex/ASCII values for both keys
  are published in `docs/shared/spoolman-integration.md` (Creality key
  material table) — neither is a secret withheld from the docs.
- ✨ **New parser** — added `_try_creality_tag()` (structured like
  `_try_tigertag()`) that decrypts and field-splits the payload: batch,
  production date code, vendor ID, filament ID / material code (mapped via
  `_CREALITY_MATERIAL_MAP`), color, spool weight (via
  `_CREALITY_LENGTH_TO_WEIGHT_G`), and serial. Registered in `parse_tag()`
  under the authenticated block-dict branch, tried right after Bambu's block
  layout, returning `tag_format: "creality"`. The old `_try_creality_cfs()`
  hex-ASCII heuristic (unauthenticated, unconfirmed, `tag_format:
  "creality_cfs"`) is kept as a fallback for raw dumps but is no longer the
  primary Creality path.
- 🐛 **Creality payload slicing aligned to `DnG-Crafts/K2-RFID`** — the AES
  parser now treats the decrypted payload as
  `date + vendor_id + batch + filament_id + color + length + serial + reserve`.
  The on-tag `filament_id` is preserved, while its trailing 5-character
  material code is still used for `_CREALITY_MATERIAL_MAP` lookup. The common
  vendor ID `0276` resolves to `Creality`; the raw ID is also stored as
  `creality_vendor_id` and the legacy `creality_supplier` alias.
- 📝 **Creality level-4 decode instrumentation** — when `debug: 4` is enabled,
  `_try_creality_tag()` now traces encrypted blocks 4-6, the decrypted payload
  as hex and printable ASCII, each parsed field, lookup results, and the exact
  reject reason when a real tag does not match the expected layout.
- 🐛 **Creality parser now ignores trailing non-ASCII bytes after the 40-byte
  structured payload** — real tag reads can decrypt to valid
  `date/vendor/batch/filament/color/length/serial/reserve` data followed by
  non-ASCII trailing bytes in the remaining encrypted block space. The parser
  now decodes only the structured first 40 bytes and logs trailing bytes at
  level 4 instead of rejecting the whole tag.
- ✨ **Key B support added to all three reader drivers** —
  `mifare_read_authenticated_blocks()` gained a `use_key_b` parameter in
  `pn532_driver.py`, `pn7160_driver.py`, and `rc522_driver.py`, threaded down
  to the existing per-driver `mifare_authenticate(..., use_key_b=...)`. None
  of them exposed Key B auth through the block-read path before this, only
  Key A.
- ♻️ **`capture_mifare_metadata()` generalized** (`tag_handler.py`) — gained
  `sectors` and `use_key_b` parameters (defaulting to the previous
  sectors-0-4/Key-A behavior) so the new Creality attempt can authenticate
  sector 1 only, with Key B, without touching the Bambu/QIDI code paths.

### 📋 PR Summary

*(Copy/paste the section below into the pull request description.)*

> ## TigerTag twin-tag pairing + Creality CFS/K1/K2 AES tag support
>
> ### Summary
> - ✨ TigerTag: extract the Twin Tag ID field and feed it into `spool_identity`, extending left-neighbor interference detection (previously Bambu-only) to TigerTag's two-tags-per-spool design — no `scan_jog.py` changes needed.
> - 🐛 Re-enabled the QIDI Box / Creality default-key MIFARE fallback that existed commented-out in `read_current_tag()`, and fixed its trigger condition so it also runs when `pycryptodome` isn't installed. ✅ Confirmed correct for QIDI Box against the community `BoxRFID-Touch` reference.
> - ✨ Added full Creality CFS/K1/K2 support: UID-derived MIFARE Key B + AES-128-ECB payload decryption (`_creality_derive_key_b()`, `_creality_decrypt_tag_data()`, `_try_creality_tag()`), with `use_key_b` support added to all three reader drivers (PN532, PN7160, RC522) to make sector-1 Key B auth possible. Key material verified against the community reference script and published in the docs.
>
> ### Test plan
> - [x] `python3 -m py_compile` on all touched files
> - [x] Standalone script cross-checks `_creality_derive_key_b()` / `_creality_decrypt_tag_data()` output against the reference script's key-generation and encrypt/decrypt logic byte-for-byte
> - [x] `parse_tag()` end-to-end dispatch test confirms a synthetic Creality block dict resolves to `tag_format: "creality"` with correct material/color/weight
> - [ ] Hardware test: real TigerTag left/right pair on adjacent gates triggers automatic clearance jog
> - [ ] Hardware test: real QIDI Box tag reads material/color via the default-key fallback
> - [ ] Hardware test: real Creality CFS/K1/K2 tag reads material/color/weight via the new Key B + AES path

---

## [1.1.0] - 07/07/2026 - WoodWorker

### Virtual Endstop — Scan-Jog Now Homes to the Tag Instead of Jogging Past It

Scan-jog's forward search used to be a blind jog-then-poll loop, so the tag's
real position was only ever known as "somewhere in the last chunk."

- Added `mmu_nfc_endstop.py`, a Klipper extra that wraps an existing
  `[nfc_gate laneN]` reader as a Happy Hare gear-rail endstop
  (`mmu.gear_rail.add_extra_endstop`, standard MCU endstop interface). While
  Happy Hare homes against it, a reactor timer polls the lane's NFC reader
  every `poll_interval` (default `0.05s`) and reports triggered the instant a
  tag UID is read — no new hardware or wiring, it borrows the reader the
  matching `[nfc_gate laneN]` already owns.
- Added `[mmu_nfc_endstop laneN]` to `nfc_reader_hw.cfg` (generated
  automatically by `install.sh` for every enabled lane) and symlinked
  `mmu_nfc_endstop.py` into Klipper's extras directory.
- Both scan-jog motion modes now search with a genuine Klipper homing move
  (`_MMU_STEP_HOMING_MOVE ENDSTOP=nfc_lane<N> STOP_ON_ENDSTOP=1 MOTOR=gear`,
  or the direct `mmu.move_filament(homing_move=1, endstop_name=...)`
  equivalent) for the full remaining scan distance, instead of jogging a fixed
  chunk and polling afterward. The move physically stops the instant the
  endstop trips. `continuous` additionally polls the reader while the move is
  in flight to build a UID hit-window, used to recenter before rich tag
  parsing; `stopped` waits for the homing move to finish, then reads once.
- Continuous scan now starts by moving on the first step instead of a
  stationary 0.0 mm poll. The previously-cached UID/spool is still stashed at
  scan start, and a UID matching that stashed UID resolves directly from the
  stashed spool instead of re-running Spoolman/rich-tag resolution.
- Fixed `uninstall.sh` to also remove the `mmu_nfc_endstop.py` symlink from
  Klipper extras; it previously only cleaned up `nfc_gate.py`/`nfc_gates/`,
  leaving the endstop extra behind after uninstall.
- Documented across `Readme.md`, `docs/shared/how-it-works.md`,
  `docs/shared/klipper-functions.md`, `docs/shared/configuration.md`,
  `docs/shared/install-uninstall.md`, and `docs/shared/architecture-decisions.md`.

### Happy Hare Filament-Position Counter Drift

Repeated `JOG_SCAN=1` runs on the same lane left Happy Hare's gear position
readout (`UNLOADED N.Nmm` in the visual status banner) drifting further from
zero every cycle, because that counter is a running total that scan-jog never
re-zeroes.

- Root cause: Happy Hare's real `MMU_LOAD`/`MMU_EJECT` sequences call
  `mmu._initialize_filament_position()` (v3's monolithic `mmu.py`; v4 renamed
  it to the public `initialize_filament_position()`) once at the start,
  before any gear moves, resetting the raw driving-stepper position
  (`mmu_toolhead.get_position()[1]`) to `0.0`. Scan-jog never calls either
  sequence — it drives the gear through Happy Hare's low-level composable
  primitives (`_MMU_STEP_HOMING_MOVE`, `_MMU_STEP_MOVE`,
  `_MMU_STEP_UNLOAD_GATE`) instead, so the reset never happens on either
  Happy Hare version.
- Fixed by calling Happy Hare's position-reset method once, at the start of
  every scan-jog session (`scan_jog.start()`). `_hh_reset_filament_position()`
  tries `_initialize_filament_position` (v3) then `initialize_filament_position`
  (v4), so the fix works on either version without needing to know which is
  installed.
- Diagnosed against the wrong Happy Hare reference tree at first — an initial
  attempt targeted v4's `mmu.drive().get_filament_position()`, which doesn't
  exist on v3 (confirmed via a console diagnostic showing `has_reset_fn=False`
  against a live `mmu_found=True` install). Re-verified against the actually
  installed v3 API before landing the real fix.

### Scan-Jog Class-Level Lock Released Too Early

- Fixed `_active_scan_gate` — the "only one gate scans at a time" guard
  checked by `manual_jog_scan()` — being cleared in `finish()` and
  `rewind_and_exit()` before those functions had finished their own cleanup
  (Happy Hare dispatch, left-neighbor restore, poll resume, LED release). A
  second `JOG_SCAN=1` issued during that window could start a new scan session
  — including its own filament-position reset and gear moves — while the
  first session's Happy Hare interaction was still in flight, corrupting
  both. `_active_scan_gate = None` now runs as the last line of both
  functions, after all other cleanup.

### Happy Hare `MMU_SELECT` Visual Banner During Scan-Jog

Every scan-jog gate selection ran `MMU_SELECT GATE=<n> QUIET=1`, which printed
Happy Hare's full gate-table + visual banner on every jog regardless of
`QUIET=1` or `wrap_suppress_visual_log()`.

- Root cause: Happy Hare v3's `cmd_MMU_SELECT` selects the gate via
  `mmu.select_gate()`, then unconditionally logs the banner through
  `self.log_info(...)` — that print reads no `QUIET` parameter and is gated
  only by `mmu.log_level`, a separate switch from the `log_visual` flag that
  `wrap_suppress_visual_log()` controls.
  - A first pass temporarily zeroed `mmu.log_level` around every Happy Hare
    call scan-jog makes. It worked but was reverted as unnecessarily broad —
    it silenced all of Happy Hare's info-level logging, not just this one
    print, for the duration of every `MMU_SELECT`/`_MMU_STEP_*` call.
  - Replaced with `select_gate_quiet()`: calls `mmu.select_gate(gate_num)`
    directly through Python (the same call `cmd_MMU_SELECT` itself makes),
    falling back to the gcode form only if that method isn't available. Every
    `MMU_SELECT` gcode call in `scan_jog.py` now goes through this helper,
    mirroring the direct-Python pattern `run_direct_continuous_jog` already
    used for gate selection.
- `wrap_suppress_visual_log()` is still used for `_MMU_STEP_*` calls, where it
  correctly suppresses `_display_visual_state()` on filament-pos-state
  transitions.

---

## [1.0.0] - 07/06/2026 - WoodWorker

### Happy Hare V4 Compatibility

Two independent fixes, for two different scan-jog trigger paths, both landed on
the same underlying symptom: scan-jog could fail to start on Happy Hare v4 while
Happy Hare reports `action=checking`.

- **Automatic gate-status polling trigger** (`scan_enabled: True`, no hook):
  added Happy Hare version detection
  (`_happy_hare_version`/`_refresh_happy_hare_version`/
  `_happy_hare_major_version`, with a lazy refresh fallback if the MMU object
  was not available yet at init) and `_happy_hare_allows_scan_action()`. The
  poll timer now treats `action=checking` as scan-safe when Happy Hare reports
  major version `>= 4`; older or unknown versions still require strict
  `action=idle`.
- **Hook-triggered / manual `JOG_SCAN=1`** (`_NFC_SCAN_JOG_PRELOAD`, Happy
  Hare's `user_post_preload_extension` hook): Happy Hare v4 invokes this hook
  while still running its own load sequence, before it unwinds back to `idle`,
  so requiring strict idle there could never succeed. The macro now sends
  `NFC GATE=<n> JOG_SCAN=1 SOURCE=AUTO`; NFC only relaxes the busy check for
  calls carrying `SOURCE=AUTO` when the detected Happy Hare major version is
  `>= 4` and the action is `checking`.
  Manual/console `JOG_SCAN=1` with no `SOURCE=AUTO` is unaffected and still
  requires strict `action == idle` on any Happy Hare version.
- Fixed Happy Hare version detection to read
  `mmu.mmu_machine.happy_hare_version`, matching the current Happy Hare object
  model, while keeping the older `mmu.version` fallback.
- Added Happy Hare version reporting to `NFC_DOCTOR`, including whether v4
  `checking` scan-jog compatibility is enabled: v4 accepts `action=idle` or
  `action=checking`; v3/pre-v4 and unknown versions accept only `action=idle`.
- Documented both mechanisms in README, `docs/shared/klipper-functions.md`, and
  `docs/shared/install-uninstall.md`.

### Spoolman-Disabled Support

- Added `spoolman_url: disabled` as a valid configuration option. When set, all
  Spoolman lookup paths short-circuit cleanly (`gate._spoolman is None` guards
  are already present throughout the Python code). Tag metadata or UID-only
  resolution continues to work; the gate map and Happy Hare filament data are
  still updated via `_NFC_SPOOL_CHANGED` when `tag_parsing: True` and the tag
  carries material/color fields.
- Added `BRAND`, `MIN_TEMP`, `DIAMETER`, and `WEIGHT` parameters to the
  `_NFC_SPOOL_CHANGED` macro dispatch for the no-Spoolman (metadata-only) path.
  All four are always sent; empty string is used when the tag does not provide a
  value. `klipper_interface.py` now reads `brand`/`vendor`, `min_temp`,
  `diameter_mm`, and `weight_g`/`spool_weight_g` from the tag metadata dict.
  The macro console message displays all fields; `MMU_GATE_MAP` continues to
  receive only the fields Happy Hare supports (NAME, MATERIAL, COLOR, TEMP).
- Added `disabled` as a third Spoolman option in the installer (lane and shared
  paths). When selected the installer sets `spoolman_url: disabled`, defaults the
  tag read mode prompt to `rich` (instead of `spoolman`), prints a note
  explaining that rich mode is required to pass filament data to Happy Hare
  without Spoolman, and skips the auto-create Spoolman spool question since there
  is no Spoolman instance to create records in.
- Fixed no-Spoolman continuous scan-jog resolution. When continuous mode finds a
  UID during motion and `tag_parsing: True`, it now runs the normal rich-tag poll
  immediately after the current move completes, before scheduling the
  overshoot-backup retry. This lets metadata-only tags resolve cleanly with
  `spoolman_url: disabled` instead of backing up first because the Spoolman UID
  lookup was unavailable.

### Reader Hardware

- Added RC522 as a supported SPI reader via `reader_type: rc522`.
  `reader_factory.py` now creates an `RC522Driver` through Klipper's SPI bus
  helper before the I2C reader path. The RC522 driver exposes the current
  reader API (`read_tag(timeout=...)`, `read_target(timeout=...)`, and target
  cleanup), and honors short continuous scan probe timeouts. RC522 uses its own
  optional `rc522_transceive_delay` setting (default `0.035`) instead of
  inheriting the slower PN532 passive-target delay.
- Added RC522 ISO14443A SELECT/cascade support and NTAG/Type-2 page reads.
  `read_target()` now returns selected target info with SAK/ATQA when SELECT
  succeeds, including 4-byte, 7-byte, and 10-byte UID cascade handling. The
  driver exposes `ntag_read_page()`, `ntag_read_user_memory()`, and
  `ntag_read_ndef_user_memory()` so `tag_handler.py` can run the existing
  rich-tag metadata resolution path for RC522 Type-2 tags. If SELECT fails
  after a valid anticollision UID, the reader falls back to the existing
  UID-only target shape so Spoolman UID lookup still works. ISO15693 remains
  unsupported on RC522.
- Added MIFARE Classic authentication and block reads to the RC522 driver.
  `mifare_authenticate()` uses the RC522 hardware `MFAuthent` (0x0E) command
  which handles the three-pass challenge/response exchange internally — no
  over-the-air auth frame is sent by the host like on PN532. After auth,
  `mifare_read_block()` uses the same `_transceive_crc` path as NTAG page
  reads; `RxCRCEn` in `ModeReg` strips the two CRC trailer bytes so the FIFO
  holds only the 16 data bytes. `mifare_read_authenticated_blocks()` matches
  the PN532 return shape (`{"uid_bytes": …, "blocks": {abs_block: bytes}}`)
  so `tag_handler.py` and the Bambu parser stay reader-agnostic. The RC522
  stops on the first auth or read failure (same policy as PN7160) because the
  hardware crypto state (`MFCrypto1On`) becomes unreliable after a rejected
  handshake; `_stop_crypto1()` clears `Status2Reg` bit 3 in the `finally`
  block so subsequent scans are never left in encrypted mode. Bambu refill
  RFID tags (MIFARE Classic 1K with HKDF-derived sector keys) are now fully
  supported on RC522.
- Added RC522 diagnostic logging for the SPI path. Init failures now log a
  warning with SPI wiring/config hints before re-raising, health checks warn
  when the reader does not respond or antenna TX bits are off, and post-REQA
  anticollision/checksum failures produce warning-level summaries with raw
  detail retained behind `debug >= 4`. Manual `SCAN=1` output now handles
  UID-only targets with no SAK value.
- Added RC522-specific low-level debug commands guarded by `low_level_debug`.
  `INIT=1` and `SCAN=1` exercise the normal RC522 init and UID scan paths;
  `RC522_DUMP_REGS=1`, `RC522_REG_READ=<reg>`,
  `RC522_REG_WRITE=<reg> VALUE=<byte>`, `RC522_ANTENNA=0|1`,
  `RC522_REQA=1`/`RC522_WAKE=1`, and
  `RC522_TRANSCEIVE='<bytes>' BIT_FRAMING=<0-7>` provide register, antenna,
  FIFO transceive, and tag-wake diagnostics without reusing PN532 ACK/ready
  semantics.
- Added orchestration-facing RC522 SPI aliases for the same diagnostics:
  `RC522_REGISTER=<reg> [VALUE=<byte>]`, `RC522_ANTENNA_ENABLE=0|1`,
  `RC522_TAG_WAKE=1`, and
  `RC522_FIFO_TRANSCEIVE='<bytes>' BIT_FRAMING=<0-7>`. These run through the
  `NFC` / `NFC_SHARED` handlers, so shared-reader and per-lane RC522 debugging
  uses the same NFC Reader command surface as init and scan.

### Console Output and Logging

- Replaced all abbreviated `HH` references with `Happy Hare` across log strings, console messages, docstrings, and user-visible status text in `nfc_manager.py`, `scan_jog.py`, `shared_preload.py`, and `hh_status.py`. `HH_SYNC` macro/command names and the `HH:MM:SS` datetime format in `log.py` are unchanged.
- Changed `[SCAN]`, `[REWIND]`, and `[OK]` tagged scan-jog messages to appear at `console_log_level: 2`, matching the warning threshold. Previously all scan-jog messages required level 3. Verbose detail lines with no tag (move-queued timing, LED state changes) still require level 3.
- Gated retry-jog position detail lines (`decode retry move queued Xmm  scan position X.X / X.Xmm`) and overshoot backup position detail lines (`continuous overshoot backup queued Xmm  scan position X.X / X.Xmm`) behind `gate._debug >= 3`. The `[WARN]` tagged console messages for these same events are unaffected and remain visible at the default warning threshold.
- Changed continuous jog move logging so it reports the actual execution path:
  `Direct Move` for direct Happy Hare MMU-toolhead moves or `MMU_TEST_MOVE` for
  the G-code fallback. The user-visible `[SCAN]` move line now fires after the
  call so it accurately reflects what was executed.

### Macro Naming Consistency

- The configured lane name (e.g. `lane0` from `[nfc_gate lane0]` in `nfc_reader_hw.cfg`) is now forwarded to all three NFC event macros as a `READER=` parameter. `_NFC_SPOOL_CHANGED`, `_NFC_SPOOL_REMOVED`, and `_NFC_TAG_NO_SPOOL` use `params.READER | default('Lane' ~ gate)` so console output reads `NFC[lane0]:` matching the section name in hardware config rather than a hardcoded `NFC gate N:` format.
- Capitalized `Gate` (capital G) in the remaining user-visible macro output lines — `NFC_HH_SYNC_CACHE` sync progress and `_NFC_SCAN_UNRESOLVED` — to match the capitalization used by `NFC_STATUS`.

### Command Fixes

- Added `NFC GATE=<#> JOG_SCAN=1` to the `NFC_HELP` output. The command existed but was only documented in the per-gate `NFC GATE=<#> HELP=1` listing.
- Fixed `NFC GATE=<#> HELP=1` incorrectly triggering the low-level PN532 debug path. `low_level_debug_requested()` checks for a `HELP` parameter, so `HELP=1` was intercepted before the per-gate help handler ran, producing spurious `polling paused for low-level PN532 debug` and `low_level_debug is disabled in config` console messages. The HELP check now runs first in `cmd_NFC`.
- Corrected the help text entry from `NFC GATE=<#> HELP` to `NFC GATE=<#> HELP=1` to match the required Klipper parameter style.

### Scan-Jog Continuous Mode — Now Default

- Promoted continuous scan-jog to the default motion mode. `scan_motion_mode: continuous` is now the out-of-the-box setting in `nfc_reader.cfg` and the Python fallback default. `scan_motion_mode: stopped` remains fully supported for marginal reader or tag alignment where continuous polling misses the tag.
- Updated `docs/shared/configuration.md`, `docs/shared/klipper-functions.md`, and `docs/shared/how-it-works.md` to reflect continuous as the default and document stopped as the alternative.

- Added opt-in continuous scan-jog mode via `scan_motion_mode: continuous`.
  Continuous mode queues forward search chunks through Happy Hare's MMU toolhead
  and polls NFC while the chunk is estimated to be moving, while preserving
  existing tag-found actions, the 0.1 second read-light hold, rewind, and
  completion logic.
- Added continuous scan settings:
  `scan_continuous_step_mm`, `scan_continuous_speed`,
  `scan_continuous_accel`, and `scan_continuous_poll_interval`.
- Changed the default rich-tag decode retry spacing from 2 mm to 5 mm and added
  continuous-mode UID hit-window recentering before rich parsing/retries when a
  UID hit does not resolve through Spoolman.
- Changed continuous-mode rich tag retry jogs from a ±sweep to a two-phase
  backward/forward walk. After the initial overshoot backup, retries now:
  (1) step backward from the backup point in `scan_decode_retry_mm` increments
  (half of `scan_decode_retry_rounds` attempts, floor at 0); then
  (2) return to the backup point and step forward in the same increment toward
  the original UID detection position (ceiling = scan total before backup),
  using the remaining attempts. The backup point and UID detection position are
  recorded as `_scan_continuous_overshoot_start_mm` and
  `_scan_continuous_overshoot_origin_mm` at backup time. Both the
  `queue_continuous_overshoot_backup` and `retry_incomplete_decode` backup paths
  record these values. The `retry_incomplete_decode` function now redirects
  continuous+overshoot retries to `queue_decode_retry_move` (same path as
  no-tag-found retries) instead of falling through to the stopped-mode ±sweep.
- Fixed a race in the first continuous chunk where `mmu.select_gate()` blocks
  for the full gate-positioning time (~0.5 s) inside `run_direct_continuous_jog`.
  Because this blocking consumed more time than the expected move duration,
  `remaining_duration` was computed as zero and the code declared the first chunk
  complete before it entered the motion queue. The second chunk was then submitted
  immediately, creating a growing motion queue backlog that shifted all subsequent
  position estimates by one full chunk (75 mm). Tags were detected one chunk
  (75 mm × number of queued moves) later than their physical location. Fixed by
  detecting when gate selection ran during the call and using `expected_duration`
  rather than `max(0, expected_duration - command_elapsed)` for that call only.
- Changed in-flight continuous probe rate. `scan_continuous_poll_interval` now
  serves as the hardware probe timeout passed to `read_tag()` in addition to its
  existing role as the timer reschedule interval. The reactor now reschedules
  immediately after each in-flight probe (returning `now` rather than
  `now + poll_interval`) so the hardware timeout is the only pacing. This raises
  the probe count per chunk from ~3 to ~10–15 (depending on speed and step size),
  reducing the effective per-probe coverage from ~28 mm to ~5 mm and making
  near-edge misses much less likely.
- Added missing commands to the global `NFC_HELP` output. The following commands
  existed and worked but did not appear in the help listing:
    `NFC GATE=<#> INIT=1` — re-run reader hardware initialisation
    `NFC GATE=<#> APPLY=1` — send cached spool to Happy Hare immediately
    `NFC GATE=<#> CLEAR_CACHE=1` — clear cached spool/UID without dispatching
    `NFC GATE=<#> HH_SYNC=1 SPOOL_ID=<n>` — seed lane cache from Happy Hare gate map
- Changed continuous in-flight scanning to perform a UID-only probe while the
  chunk is moving, then defer Spoolman lookup and rich tag parsing until the
  current chunk has finished.
- Switched continuous scan behavior to try resolving a detected UID first;
  only if tag resolution fails is the reverse/overshoot backup jog queued.
- Documented the tested continuous profile: 50 mm chunks at 150 mm/s with
  2000 mm/s^2 acceleration and a 0.05 s in-flight tag-check cadence.
- Optimized the baseline continuous scan configuration for optimal speed while
  minimizing overshoot, balancing chunk pacing and probe cadence to reduce
  missed tags without introducing extra backtracking.
- Added direct Happy Hare MMU-toolhead forward jog support for continuous scan,
  with `MMU_TEST_MOVE WAIT=0` retained as a compatibility fallback.
- Reduced repeated continuous-mode search LED calls by removing the top-of-loop
  LED reapply while keeping the post-move reassertion.
- Fixed scan-jog direct console messages so they respect `console_output` and
  `console_log_level` instead of always calling `respond_info`.

---

## [0.9.23] - 06/01/2026 - WoodWorker

### Installer Prompt Cleanup

- Removed the installer terminal theme/profile prompt and the `-p` profile color option.
- Simplified installer prompt emphasis to default terminal color with bold text only; no custom cyan/green/yellow/magenta highlight colors are used.
- Added a per-lane reader I2C bus prompt. The installer now writes the selected bus to the base `[nfc_gate]`, comments/uncomments the SLB and EBB preset lines, and uses a custom active bus line when the user enters a different hardware bus.
- Added a per-lane reader MCU prefix prompt. The installer defaults to `mmu` and writes lane hardware sections as `mmu0`, `mmu1`, etc.; entering `lane` writes `lane0`, `lane1`, etc.
- Added an installer warning when software-I2C sensor config is detected in printer config files, with the hardware `i2c_bus` line users should apply to sensor sections such as `emu_macros.cfg`.
- Added optional `scan_jog_max` for scan-jog. When set, NFC uses that fixed maximum travel distance instead of reading Happy Hare Bowden calibration. The installer now asks lane-reader users whether to set `scan_jog_max` with a default of `480.0mm` or keep using per-lane Bowden lengths.

### Install / Uninstall Cutover

- Changed the public install target to `Happy-Hare-RFID-Reader` cloned into `~/rfid-reader`.
- Updated Moonraker update-manager generation to use `[update_manager Happy-Hare-RFID-Reader]`, matching the public repo name exactly.
- Added cleanup for old beta Moonraker sections: `[update_manager emu_nfc_reader]`, `[update_manager happy_hare_rfid_reader]`, and `[update_manager Happy-Hare-rfid-reader]`.
- Added beta cutover handling for legacy `~/emu-nfc-reader` installs. The installer now prompts before cleanup, backs up `~/printer_data/config/nfc/`, backs up `moonraker.conf`, removes old Klipper symlinks, removes the legacy repo, and continues with a fresh `~/rfid-reader` install.
- Removed installer-driven update behavior for existing checkouts. Users update with `git pull` before rerunning `bash install.sh`; the installer no longer runs `git pull`, `git fetch`, or sparse-checkout updates during normal installs.
- Updated uninstall behavior to prompt for local repo checkout removal at the end of `bash uninstall.sh`. The default answer is yes; answering `n` keeps `~/rfid-reader`.
- Kept uninstall repo removal guarded so it only removes the expected `~/rfid-reader` git checkout.
- Added local simulation scripts for install and uninstall testing without touching the real repo or public GitHub: `tests/simulate_rfid_reader_install.sh` and `tests/simulate_rfid_reader_uninstall.sh`.
- Updated public README, private README, install/uninstall docs, design notes, and regression tests for the new install path, uninstall prompt, Moonraker section, and public sync target.

### Scan-Jog Safety

- Blocked manual `NFC GATE=<gate> JOG_SCAN=1` when Happy Hare reports the selected gate as empty (`gate_status=0`). NFC now returns a single console error that `jog_scan` is not enabled for an empty gate and does not start motion.
- Changed normal scan-jog rewind/no-tag status messages back to `[REWIND]`/`[OK]` severity so ordinary rewind flow is not reported as `[WARN]`.
- Changed `_NFC_TAG_NO_SPOOL` console guidance to use a red `[ERROR]` heading while keeping the message in the macro alongside the Happy Hare gate-map cleanup.

### Shared Reader Bypass

- Moved the bypass active-spool console confirmation out of `_NFC_SHARED_BYPASS_SPOOL_CHANGED` and into the Python shared-reader path next to the matching `nfc_reader.log` entry. The macro now only calls Moonraker's `spoolman_set_active_spool`.

---

## [0.9.24] - 05/27/2026 - WoodWorker

### Shared Reader LED Target Guard

- Fixed shared-reader legacy LED gate targeting so an MCU-derived index outside Happy Hare's configured gate range no longer sends `MMU_SET_LED GATE=<invalid>`. NFC now falls back to whole-unit LED control for that effect, preventing HH errors such as `The value '4' is not valid for GATE`.
- Documented the fallback in `nfc_reader_shared.cfg` and the shared-reader design notes.
- Added stronger shared-reader hook diagnostics. `NFC_DOCTOR`, startup warnings, and shared pending timeouts now call out when `mmu_macro_vars.cfg` is still wired to the per-lane `NFC JOG_SCAN=1` hook instead of `_NFC_SHARED_PRELOAD`.
- Updated shared-reader docs and config comments so the Happy Hare hook is consistently documented as `variable_user_post_preload_extension: '_NFC_SHARED_PRELOAD'`.
- Restored the shared pending-spool 80% warning as an explicit Klipper console message while keeping the matching entry in `nfc_reader.log`.
- Made the shared 80% pending warning fire from the main poll timer as well as the warning timer, and changed the warning LED effect to avoid HH `DURATION` blocking. `_NFC_SHARED_PRELOAD` now releases warning LED feedback as soon as preload validation begins.

---

## [0.9.23] - 05/26/2026 - WoodWorker

### Shared Reader LED Duration Contract

- Changed normal shared-reader read and staged-ready LED feedback so NFC calls `MMU_SET_LED UNIT=0 EXIT_EFFECT=<effect>` without `DURATION`. These effects must remain interruptible by the next shared-reader state, such as ready, unresolved, warning, loaded, cancel, replace, or timeout.
- Added a local shared-read LED failsafe. If a normal shared read effect starts and no follow-up state takes LED ownership, NFC releases back to Happy Hare with `MMU_GATE_MAP QUIET=1` after `read_effect_duration`.
- Added HH-control restoration on shared read timeout, manual `NFC_SHARED READ=0`, reader failure, disconnect, and print-start polling suspension when no spool is pending.
- Added `NFC_SHARED RESET=1` as a recovery command that clears pending/read/preload shared state, restores HH LED ownership, and restarts shared polling.
- Kept HH `DURATION` only for standalone shared LED feedback: `NFC_SHARED LED_TEST=1`, unresolved feedback, and bypass-ready confirmation. Pending-warning feedback is interruptible so Happy Hare can take LEDs back when preload starts.
- Documented the Happy Hare `MMU_SET_LED DURATION=` behavior: when `DURATION` is passed, HH sets `pending_update[unit] = True`; while that timer is active, later LED effect requests for the same unit are ignored by `_set_led()`.
- Removed stale `ready_effect_duration` documentation for the normal staged-ready path. Staged-ready feedback now follows the shared-reader lifecycle and releases with `MMU_GATE_MAP QUIET=1` on preload commit, cancel, replace, or pending timeout.
- Updated shared-reader tests to assert the interruptible versus timeout-bound LED behavior.

### Repo Hygiene

- Stopped tracking `.claude/settings.json` and added it to `.gitignore` so local agent/editor settings do not appear in repo changes.

---

## [0.9.22] - 05/24/2026 - WoodWorker

### Spoolman UID Registration

- Added `NFC_Register UID=<uid> Spool_id=<id>` so a known NFC UID can be assigned to an existing Spoolman spool directly from the printer console.
- The command validates Spoolman availability, confirms the target spool exists, writes the configured `spoolman_rfid_key`, and clears NFC's UID lookup cache. It intentionally does not call `MMU_SPOOLMAN REFRESH` inline because that Happy Hare path can block Klipper after the Spoolman write succeeds.
- Avoided the full duplicate-UID scan from the Klipper command path so `NFC_REGISTER` stays light.
- Stopped reading the Spoolman PATCH response body after UID registration. Spoolman applies the RFID field update before the body is needed, and waiting for a slow/kept-open body can freeze Klipper's reactor after the UID has already been saved.
- Added command help, README, message documentation, and regression coverage for successful registration and missing-spool rejection.
- Fixed `NFC_REGISTER` help/error rendering so the command appears with the same uppercase styling as other commands, avoids console-swallowed angle-bracket placeholders, and emits command errors once while still writing them to `nfc_reader.log`.

### Lane LED Test Commands

- Added `NFC GATE=<n> LED_TEST=1` to test the configured per-lane tag-read effect on one gate.
- Added `NFC_LED_TEST ALL=1` to test the configured per-lane tag-read effect on every enabled lane reader, with a default 0.20 s chase delay between gates.
- Added `LED_effect_mgr.py` as the NFC/Happy Hare LED contract boundary. Lane scan-jog, shared-reader feedback, and LED test commands now route LED effect naming, public `MMU_SET_LED` effect calls, and HH release requests through the shared manager.
- Completed the LED contract layer with semantic event helpers (`scan_start`, `tag_read`, `rewind`, `spool_ready`, `unresolved`, `auto_create`, `warning`, and `led_test`) and moved lane LED test cycle scheduling into `LED_effect_mgr.py`.
- Fixed `NFC GATE=<n> LED_TEST=1` so the lane LED test dispatches through Klipper's async callback path instead of running nested GCode from inside the command handler.
- Added `CYCLES=<count>` to per-gate and all-lane LED tests. The default is `2`, and each cycle starts the configured base effect with `MMU_SET_LED GATE=<n> EXIT_EFFECT=<effect>`; NFC no longer sends a default-effect restore between cycles and ends the sequence with `MMU_GATE_MAP QUIET=1`.
- Updated command help, README, message docs, and tests for the new LED test commands.

---

## [0.9.21] - 05/23/2026 - WoodWorker

### Scan-Jog LED Reliability

- Added `_NFC_SCAN_JOG_PRELOAD`, a per-lane Happy Hare post-preload hook macro that starts `mmu_clockwise_slow_exit_<gate>` immediately before launching `NFC GATE=<gate> JOG_SCAN=1`.
- Added a delayed scan LED reassert timer so the per-gate clockwise search effect is reapplied after Happy Hare's own LED refreshes from `MMU_GATE_MAP`, `MMU_SELECT`, and `MMU_TEST_MOVE`.
- Reasserted the searching effect after scan prep, each scan step, each jog move, and decode-retry moves so the NFC scan state keeps visible control of the active gate while scan-jog is running.
- Cancelled pending LED reassert timers when scan-jog exits, rewinds, disconnects, or intentionally hands LED control back to Happy Hare.
- Added a short visible tag-read hold before rewind so `mmu_RFID_read_exit_N` can play before the rewind effect starts.
- Kept rewind LED feedback active through the rewind move and released back to Happy Hare only after parking/polling cleanup completes.
- Updated per-lane hook documentation to wire `variable_user_post_preload_extension: '_NFC_SCAN_JOG_PRELOAD'` instead of calling `NFC JOG_SCAN=1` directly.
- Added regression coverage for the hook wrapper ordering, delayed search-effect reassert, and updated scan-jog timing expectations around the tag-read hold.

### Config Defaults

- Fixed default inheritance for the per-lane LED effect names so base `[nfc_gate]` values are available to lane instances unless explicitly overridden.

### Installer

- Stopped installing `nfc_reader_shared.cfg` during lane-reader installs. Shared-reader config is now written only when the user selects the shared-reader install path.
- Reader-type detection now defaults to `shared` only when `printer.cfg` actively includes a shared-reader config, or when a shared-reader config exists without a lane hardware config. Old shared-reader template files no longer force a lane reinstall to default to shared.
- Made interactive choice highlighting consistent: the default selection is highlighted in both the description text and bracket prompt; non-default choices remain unhighlighted.

---

## [0.9.20] - 05/23/2026 - WoodWorker

### Per-Gate LED Feedback — Scan-Jog and Spool Resolution

Added per-gate LED effects for per-lane readers across three events. All effects target only the active gate using HH's `_exit_N` naming convention (`_MMU_SET_LED_EFFECT EFFECT={name}_exit_{gate} REPLACE=1`).

**Scan-jog state machine** (`scan_jog.py`):

| Phase | Effect fired |
|---|---|
| Searching (first scan step, deferred from `start()`) | `mmu_clockwise_slow_exit_N` |
| Tag read confirmed | `mmu_RFID_read_exit_N` |
| Rewind started (tag found or no-tag abort) | `mmu_anticlock_fast_exit_N` |
| Park complete / polling resumed | `MMU_GATE_MAP QUIET=1` → returns LED control to Happy Hare |

**Spool resolution** (`tag_handler.py`):

| Event | Effect fired |
|---|---|
| Spoolman auto-create in progress | `mmu_RFID_creating_exit_N` (stopped when API call returns) |
| Tag found but cannot be resolved to a spool | `mmu_RFID_unresolved_exit_N` (self-terminates) |

- The shared reader already handled `mmu_RFID_creating` and `mmu_RFID_unresolved` via its own effect scheduler. Per-lane effects now use the same `tag_handler.py` call sites, guarded by `not getattr(gate, '_shared', False)`.
- Effect names are configurable in `nfc_reader.cfg` via five new keys in the base `[nfc_gate]` section: `scan_searching_effect`, `scan_tag_read_effect`, `scan_rewind_effect`, `lane_auto_create_effect`, `lane_unresolved_effect`. Per-lane sections inherit these from the base or can override individually. Set any key to empty to disable that effect.
- Module constants `LED_SEARCHING`, `LED_TAG_READ`, `LED_REWINDING` in `scan_jog.py` and `LED_AUTO_CREATING`, `LED_UNRESOLVED` in `tag_handler.py` serve as code-level fallbacks only; the live effect name is always read from `gate._xxx_effect` at runtime.
- The searching effect is deferred to the first reactor timer step (`run_pending_hh_prep`) so it fires from timer context where `gcode.run_script()` is safe.
- Required: all five base effects must be defined with `define_on: gates` (or `define_on: gates, exit`) in the HH LED config so Klipper generates per-gate `_exit_N` variants automatically. `mmu_RFID_read`, `mmu_RFID_creating`, and `mmu_RFID_unresolved` are already defined this way in `nfc_macros.cfg`.

---

## [0.9.19] - 05/22/2026 - WoodWorker

### Reader Diagnostics

- Added `NFC_DOCTOR`, a no-motion setup check that reports configured lane readers, the shared reader, disabled readers, Spoolman availability, shared-reader Happy Hare hook wiring, and static configuration warnings.
- Added startup warnings for configuration combinations that are accepted by Klipper but unlikely to work as intended, including rich-tag reads with tag parsing disabled, auto-create with tag parsing disabled, and auto-create without a usable Spoolman URL.

### Config Compatibility

- Added `enabled: False` support for per-lane and shared `[nfc_gate ...]` sections. Disabled readers keep their config block in place but skip PN532/I2C initialization, command registration, polling, and scan setup while still appearing in status and doctor output.
- Updated the hardware and shared-reader config templates, installer-generated configs, and configuration docs to show the new `enabled` option.

### Documentation and Tests

- Added `NFC_DOCTOR` to the README command list and the Klipper command reference.
- Added regression coverage for doctor command registration, disabled-lane reporting, and static warning generation. Full test suite passes with `376` tests.

---

## [0.9.18] - 05/20/2026 - WoodWorker

### Test Suite — Macro Tests Updated

- Rewrote 4 tests across `test_nfc_macros_config.py` and `test_shared_reader.py` that were asserting old `_NFC_SHARED_PRELOAD` behavior (`MMU_SELECT`, `MMU_GATE_MAP`, `MMU_SPOOLMAN`, `auto_created`). Tests now verify the validate-and-commit-only pattern and assert that gate map calls are absent from the macro.

### Documentation — Config Inheritance Clarified

- Added a `docs/shared/configuration.md` example showing top-level `[nfc_gate]` defaults and per-lane `[nfc_gate laneN]` overrides for values like `i2c_address`, `i2c_bus`, and `scan_enabled`.
- Removed obsolete LED holder files from `NFC Mounting Bracket`, preserving only `LED_holder_with_NFC_Bambu_height v3.step`.

---

## [0.9.17] - 05/20/2026 - WoodWorker

### Shared Preload Macro — Root Cause Fix

- Removed all `MMU_GATE_MAP`, `MMU_SELECT`, and `MMU_SPOOLMAN` calls from `_NFC_SHARED_PRELOAD`. Python stages `MMU_GATE_MAP NEXT_SPOOLID` at tag-read time; Happy Hare processes it during the pregate load and owns the gate map entry by the time `user_post_preload_extension` fires. The macro re-assigning the gate map inside the hook was interfering with HH's finalized state, causing Spoolman ID to remain `-1` in the gate editor even though filament metadata was correct. The macro is now validate-and-commit only: `NFC_SHARED PRELOAD_CHECK=1` and `NFC_SHARED PRELOAD_COMMIT=1`.
- Removed `MMU_SELECT GATE={target_gate}` — HH has already selected the gate before the post-preload hook fires; re-selecting inside the hook can reset gate state and halt macro execution before `PRELOAD_CHECK` runs.

### Shared Preload Macro Cleanup (earlier in session)

- Removed the `auto_created` guard and redundant `MMU_SPOOLMAN REFRESH=1 QUIET=1` — Python already issues the refresh at tag-resolution time before staging `NEXT_SPOOLID`.
- Replaced `MMU_SPOOLMAN SPOOLID={spool_id} GATE={target_gate} QUIET=1` with `MMU_SPOOLMAN SYNC=1 QUIET=1` to match the pattern used by `_NFC_SPOOL_CHANGED`.

### Documentation — First-Install Gaps Fixed

- Added "Shared Reader — Additional Required Steps" section to `install-uninstall.md` covering the two things that silently break a first-time shared-reader install: wiring `variable_user_post_preload_extension: '_NFC_SHARED_PRELOAD'` in `mmu_macro_vars.cfg`, and setting `pending_spool_id_timeout` in `mmu_parameters.cfg` (the 30 s fallback is too short for normal use).
- Fixed stale description in `shared-reader.md` ("What it does" and step 5 of the load flow) that still described the old macro behaviour — selecting the gate and issuing `MMU_GATE_MAP`/`MMU_SPOOLMAN` directly. Both now accurately describe the validate-and-commit-only macro.

---

## [05/20/2026] - WoodWorker

### Shared Reader LEDs

- Changed shared-reader ready, bypass-ready, and warning LED defaults from strobes to breathing-style effects so staged/ready feedback is calmer while the EMU waits.
- Updated `_NFC_SHARED_PRELOAD` to follow the per-lane assignment pattern more closely: select the hook gate, validate/commit the pending spool, apply the local Happy Hare gate map, and directly set the Spoolman gate assignment with `MMU_SPOOLMAN SPOOLID=<n> GATE=<n> QUIET=1`.
- Shared preload now mirrors the per-lane auto-created spool path by running `MMU_SPOOLMAN REFRESH=1 QUIET=1` only when the pending shared-reader spool was newly created, before applying the gate map assignment.
- Removed the obsolete duplicated shared-reader "already assigned" macro branch and the broad gate-map refresh from the shared preload success path.
- `_NFC_SHARED_PRELOAD` now prefers Happy Hare's hook-provided `GATE=<n>` and selects that gate before preload validation, preventing a previously selected lane from receiving the shared reader's resolved spool.
- Fixed bypass unresolved-tag feedback replaying across the shared reader's missed-resolution retries. The unresolved red LED effect now starts only once for an unresolved tag sequence, so bypass mode no longer appears to flash 6 times from three repeated attempts.
- Changed `mmu_RFID_unresolved` to exactly 2 red flashes (`strobe 2 2`) and updated shared-reader config comments, installer text, and docs to match.
- Kept bypass-ready confirmation bounded at 2 seconds and ensured scheduled LED timers stop the exact effect that was started.
- Added configurable shared-reader LED stop durations (`read_effect_duration`, `bypass_read_effect_duration`, `ready_effect_duration`, `bypass_ready_effect_duration`, and `unresolved_effect_duration`) next to their related effect names in `nfc_reader_shared.cfg`.
- Expanded `nfc_reader.cfg` scan-jog comments to document polling lane readers, `NFC JOG_SCAN=1` hook-triggered lane readers, shared-reader preload mode, and the hybrid lane-reader plus shared-reader bypass setup.
- Updated scan-jog's `_NFC_GATE_CLEAR_CACHE` preflight to call `MMU_SPOOLMAN GATE=<n> QUIET=1` before clearing the local HH gate spool ID, so stale Spoolman edit-dialog gate/location assignments are removed before NFC applies the newly read spool.

### Tests

- Added regression coverage proving repeated unresolved shared-reader events only start the red unresolved LED effect once.
- Added regression coverage for custom shared-reader LED effect durations.
- Added static coverage for the scan-jog preflight Spoolman gate unset.

---

## [0.9.15] - 05/19/2026 - WoodWorker

### Pending Spool Timeout Now Sourced from Happy Hare

- Removed `shared_pending_timeout` as a configurable key in `[nfc_gate shared]`. The pending window is now read automatically from Happy Hare's `mmu_parameters.cfg` (`[mmu] → pending_spool_id_timeout`) at Klipper connect time via the Klipper `configfile` object. Falls back to 30 s if the value cannot be read.
- `nfc_reader_shared.cfg` and the installer-generated shared config now carry a comment directing users to set `pending_spool_id_timeout` in `mmu_parameters.cfg` instead of a local override.
- Documentation updated across `docs/shared/configuration.md`, `docs/shared/shared-reader.md`, `docs/shared/klipper-functions.md`, and the design docs to reference the HH parameter.

---

## [05/19/2026] - WoodWorker

### Shared Reader Preload — Spool ID Timing Fix

- `MMU_GATE_MAP NEXT_SPOOLID` is now staged in Python immediately when the NFC tag resolves to a spool, rather than inside the `_NFC_SHARED_PRELOAD` GCode macro. Previously the macro ran AFTER Happy Hare had already finalized the gate map entry for the loaded gate, so the spool ID was never applied to the active gate and it displayed `Id: n/a`.
- For auto-created spools, `MMU_SPOOLMAN REFRESH=1` is also dispatched at resolution time (before `NEXT_SPOOLID`) so Happy Hare knows about the new spool before the hint is staged.
- Removed the now-redundant `MMU_GATE_MAP NEXT_SPOOLID` and `MMU_SPOOLMAN REFRESH` lines from `_NFC_SHARED_PRELOAD`; the macro now only handles validation (`PRELOAD_CHECK`) and commit (`PRELOAD_COMMIT`).
- If Happy Hare already shows the staged shared-reader spool assigned to a loaded gate, `_NFC_SHARED_PRELOAD` now treats that as success and commits the pending NFC read without clearing the Happy Hare gate map. This fixes same-lane eject/read/reinsert flows where the spool briefly loaded and then gate 4 was reset to `Empty` / `Id: n/a`.
- When no spool is pending at preload time (either nothing was tapped or the UID was unresolved), `_NFC_SHARED_PRELOAD` now clears the target gate's map to `SPOOLID=-1 COLOR=FFFFFF55` before firing the `force_spool_id` advisory. Previously the gate retained the previous spool's color and ID so the EMU showed the wrong spool instead of the shadowed unknown state.

### LED Effects

- `mmu_RFID_read` changed from 3 flashes to 1 flash on tag scan, differentiating it clearly from `mmu_RFID_bypass_ready` (3 flashes = bypass spool confirmed).
- Bypass-ready/shared-ready LED effects are now scheduled to stop after 4 seconds when used for immediate bypass spool confirmation, so the confirmation flash does not run indefinitely.
- The shared-reader 80% pending-timeout warning now defaults to `mmu_RFID_warning`, switches from the ready LED to the warning LED at the warning point, and re-arms itself for the actual timeout so expiry cleanup cannot be missed.
- When a shared-reader pending spool expires, NFC now stops the warning LED, issues `MMU_GATE_MAP QUIET=1` to restore Happy Hare steady-state LEDs, and restarts shared polling so another spool can be scanned immediately.

### Shared Reader Installer

- Shared-reader installs no longer inject `shared_led_segment` into generated config; users can own that setting directly in `nfc_reader_shared.cfg`.
- Re-running the installer in shared-reader mode now skips `nfc_reader_hw.cfg` lane-section merging so pure shared installs do not unexpectedly append lane sections.
- Shared-reader installs now update only the selected hardware/startup keys in `[nfc_gate shared]`, preserving user-edited LED settings and comments.
- The installer no longer regenerates the full shared-reader config on every shared install. It now uses targeted `set_config_value` updates for `i2c_mcu`, `i2c_bus`, `shared`, and `startup_polling`.
- Added `detect_mmu_led_unit()` to the installer. It reads `[mmu_leds <name>]` from `mmu_hardware.cfg` and exposes the real unit name so the post-install summary shows the correct whole-chain effect name (e.g., `unit0_mmu_RFID_read_exit`) instead of a hardcoded placeholder.

### Shared Reader LEDs

- `shared_led_segment: exit` keeps the whole-segment LED behavior (`unit0_mmu_RFID_read_exit`).
- `shared_led_segment: gate` restores the legacy single-lane LED behavior (`mmu_RFID_read_exit_N`).
- `shared_led_segment` is normalized to lowercase at load time, so values like `Gate` and `EXIT` resolve consistently.
- `nfc_reader_shared.cfg` now documents `shared_led_segment` as an LED target selector: `exit`/`entry`/`status` target a whole segment, while `gate` targets the legacy single lane.

### Happy Hare Bypass

- Shared-reader spool resolution now detects Happy Hare bypass mode (`printer.mmu.tool == -2`) and immediately sets Moonraker's active Spoolman spool through `_NFC_SHARED_BYPASS_SPOOL_CHANGED`.
- When bypass is active, the shared reader does not stage `NEXT_SPOOLID` or wait for the Happy Hare preload hook; normal shared preload behavior is unchanged for MMU gates.

### Config Compatibility

- Replaced raw CSS hex colors in `_NFC_SPOOL_CHANGED` console messages with named colors so Klipper's config/template parser does not treat `#` as a comment marker and halt during startup.
- Unknown/no-spool NFC metadata now uses `COLOR=FFFFFF55` consistently, matching the scan-unresolved placeholder color.
- Shared-reader preload transaction warnings now use the standard NFC console color tags instead of raising Klipper command errors, avoiding red `!! Error running _NFC_SHARED_PRELOAD` wrappers for nonfatal bridge warnings.
- NFC logger console output now avoids Klipper `RESPOND TYPE=error` / `TYPE=command` coloring and uses the NFC HTML tag colors for `[OK]`, `[WARN]`, and `[ERROR]` consistently.

### Log Rotation and Pruning

- Fixed archive accumulation: `_prune_old_archives` now runs at every Klipper startup, not only when the midnight-crossing `_rotate` path fires. Previously, Klipper restarts before midnight would rename the old log file but never prune, so archives built up indefinitely.
- Retention remains 7 days / 7 archives; the bug was the pruning never ran, not the threshold.

### Console Output and Logging Consistency

- All log message prefixes standardized to `NFC[name]: ` across every module (`nfc_manager.py`, `shared_preload.py`, `tag_handler.py`, `scan_jog.py`). Previously the format varied between `nfc_gate: [name] `, `nfc_gate: `, and bare messages — making it hard to filter logs for a specific gate.
- Switched logger console dispatch away from generated `RESPOND` scripts and onto direct `gcode.respond_info()` calls. This prevents Fluidd/Mainsail from showing `echo:` or Klipper-added prefixes on NFC status lines, while still allowing the NFC logger to color `[OK]`, `[WARN]`, and `[ERROR]` consistently.
- Shared-reader pending warnings and timeout messages now use the same themed prefix format as the rest of the console output: `[WARN] NFC[shared]: ...` and `[ERROR] NFC[shared]: ...`. This fixes the old `NFC [WARN] [shared]` ordering and removes leftover white `[shared]` lane styling.
- Scan-jog and per-lane command replies now use the same themed `NFC[lane]: ...` console prefix, including READ/POLL replies and rewind messages. Logger console output also normalizes older internal `[lane]: ...` messages before they reach the UI.
- `shared_preload.py` fully converted from `gcmd.respond_info()` to `logger.info/warning/error()`. All `PRELOAD_CHECK`, `PRELOAD_COMMIT`, and `PRELOAD_CLEAR_ASSIGNED` feedback now routes through the shared logger so the three output destinations (nfc_reader.log, klippy.log forwarding, and Klipper console) are always in sync.

### Tests

- Added regression coverage for shared LED target naming, including whole-segment and legacy single-gate modes.
- Added regression coverage for shared-reader bypass detection and immediate active-spool assignment.
- Added installer checks to keep `shared_led_segment` out of generated shared config and prevent shared-only installs from merging lane hardware sections.
- Added a macro config guard so `action_respond_info` lines do not use raw CSS hex color literals.
- Added logger regression coverage for direct console dispatch, NFC-themed warning ordering, green `[OK]`, yellow `[WARN]`, red `[ERROR]`, and removal of the old white lane-name styling.
- Added regression coverage for scan-jog rewind and per-lane READ/POLL console prefixes.

---

## [05/18/2026]

### Shared Reader Improvements

- Added full shared-reader command coverage through `NFC_SHARED`, including help, status, summary, cancel, replace, LED test, cache sync, polling, scan, and raw poll actions.
- `NFC_SHARED HELP=1` now documents the required `=1` action flag style so commands match Klipper's parser and avoid malformed bare commands.
- Shared-reader installs now include the base `nfc_reader.cfg` along with `nfc_reader_shared.cfg`, so the standard NFC commands and shared commands are both available after install.
- Shared-reader polling uses the scan-jog reader interval, not the slower base polling interval. The config comments now call this out so tuning the shared reader is less mysterious.
- The shared reader now prints a green `[OK]` line as soon as a tag is successfully read and staged, before the later Happy Hare preload messages.
- `nfc_reader_shared.cfg` now defaults `i2c_mcu: mmu` so the most common wiring works without editing the hardware config.

### LED Behavior

- Shared reader events now flash **all MMU gate exit LEDs simultaneously** instead of a single per-gate LED. All five `mmu_RFID_*` effects now use `define_on: gates, exit`, which creates both per-gate effects (used by per-lane readers) and a whole-chain effect that targets every gate at once (used by the shared reader).
- Fixed indefinitely looping unresolved-tag strobe — it now plays a fixed number of flashes and stops cleanly.
- `mmu_RFID_ready` (green strobe) now persists continuously while a spool is staged and waiting to load; previously it blinked twice and stopped.
- Added `mmu_RFID_warning` amber strobe: plays when the pending timeout is 80% elapsed, giving the user a visible countdown before the spool is dropped.
- Amber warning strobe stops exactly when the pending timeout expires — no overshoot.
- After all NFC effects finish, HH gate LEDs are restored via `MMU_GATE_MAP QUIET=1` only when no spool is pending, preventing HH's gate repaint from killing the active ready effect mid-wait.
- On pending timeout, polling always restarts automatically (equivalent to issuing `NFC_SHARED REPLACE=1`).

### Klipper Deadlock Fix

- Eliminated a class of Klipper deadlocks caused by calling `run_script()` from inside GCode command handlers. All LED, respond, and HH gate-map calls that originate from GCode handlers are now deferred via `register_async_callback`. Affected commands: `NFC_SHARED LED_TEST`, `REPLACE`, `CANCEL`, `CLEAR`, `PRELOAD_CLEAR_ASSIGNED`.

### Happy Hare Preload Behavior

- Fixed the pure shared-reader stale assignment path. If Happy Hare still has a spool assigned to a gate when the shared reader stages that same spool, NFC now clears the stale Happy Hare gate assignment and gets ready for the next tag.
- Hybrid installs are still protected: when per-lane readers are present, the shared reader does not overwrite or clear legitimate per-lane assignments.
- `NFC_SHARED PRELOAD_CLEAR_ASSIGNED=1` now receives the assigned gate number so the automatic cleanup can target the correct Happy Hare gate.
- `force_spool_id` no longer throws a Klipper command error when no spool is staged. It now shows one red `[ERROR]` console advisory instead of duplicated `!!` error lines.
- `_NFC_SHARED_PRELOAD` macro cross-checks `gate_status` when evaluating already-assigned spools — a gate with status 0 (filament absent) is no longer treated as occupied, fixing the case where a spool ejected from a gate with no per-lane reader left a stale HH assignment that blocked future loads of the same spool.

### Console Output

- All NFC console messages now route through the logger rather than inline `RESPOND` GCode calls, eliminating `echo:` format output and removing a second source of deadlocks.
- Standardized console tag colors:
  - `[OK]` renders green.
  - `[WARN]` renders yellow.
  - `[ERROR]` renders red text without forcing a Klipper error unless the command truly fails.
- Reduced duplicate shared-reader warnings by keeping recovered stale-assignment details in the internal log and showing only one concise console warning.
- Replaced stop-sign precondition glyphs with `[ERROR]` for clearer, consistent console messages.

### Documentation

- README and quick-install guide updated with the correct Happy Hare hook parameter: `variable_user_post_preload_extension: '_NFC_SHARED_PRELOAD'` in `mmu_macro_vars.cfg`.
- Install instructions now list the required config includes for shared-reader installs.
- Command reference updated to cover `NFC_SHARED` commands users are expected to run day-to-day.

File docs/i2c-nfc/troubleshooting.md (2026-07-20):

# Troubleshooting

[← README](../../Readme.md) | [Setup](setup.md) | [Expert Debug →](../shared/expert-low-level-i2c-debugging.md)

---

## Quick Links

- [Start Here: MCU Firmware](#start-here-mcu-firmware)
- [Klipper Won't Start - Config Errors](#klipper-wont-start--config-errors)
- [PN532 Not Responding](#pn532-not-responding)
- [PN7160 Not Responding](#pn7160-not-responding)
  - [`connect_nci failed: I2C label=CORE_RESET status=START_NACK`](#connect_nci-failed-i2c-labelcore_reset-statusstart_nack)
  - [`Unable to obtain 'i2c_read_response' response`](#unable-to-obtain-i2c_read_response-response)
- [PN5180 Not Responding](#pn5180-not-responding)
- [BME280 Fails After PN532 Is Added](#bme280-fails-after-pn532-is-added)
- [Tag Detected But No Spool Found](#tag-detected-but-no-spool-found)
- [False Spool Removals](#false-spool-removals)
- [Happy Hare Not Updating](#happy-hare-not-updating)
- [Diagnostic Command Summary](#diagnostic-command-summary)

---

## Start Here: MCU Firmware

> [!CAUTION]
> **The most common source of NFC reader failures is stale lane MCU firmware.**
>
> If you updated the Klipper host but didn't rebuild and flash the EBB42 firmware, the MCU and host are running different protocol versions. I2C failures from this look exactly like hardware problems — bad wiring, wrong mode, broken module.
>
> **Rebuild and flash every lane MCU. Then try again.**

---

## Klipper Won't Start — Config Errors

### `Unknown config section 'nfc_gate'`

The NFC Python module didn't load. Check that the symlinks exist:

```bash
ls -la ~/klipper/klippy/extras/nfc_gate.py
ls -la ~/klipper/klippy/extras/nfc_gates/
```

If missing, run repair:
```bash
cd ~/rfid-reader && bash install.sh -r
```

---

### `Section 'nfc_gate lane0' defined before 'nfc_gate' base section`

The includes in `printer.cfg` are in the wrong order. It must be:

```ini
[include nfc/nfc_reader.cfg]     ← first
[include nfc/nfc_macros.cfg]
[include nfc/nfc_reader_hw.cfg]    ← last
```

---

### `Option 'i2c_mcu' in section 'nfc_gate lane0' is not a valid config option`

Same cause as above — the base `[nfc_gate]` section wasn't loaded before the lane section. Fix the include order.

---

## PN532 Not Responding

### `PN532 did not respond`

The reader isn't answering on the I2C bus at all.

Check in this order:

1. **I2C mode** — SEL0=1, SEL1=0 on the PN532 DIP switches. This is the most common mistake.
2. **Voltage** — VCC is 3.3V (or 5V through onboard regulator if your board supports it, but SDA/SCL must be 3.3V)
3. **GND** — shared between PN532 and lane MCU
4. **SDA/SCL not swapped** — PB3=SCL, PB4=SDA on the EBB42
5. **`i2c_mcu` name** — matches exactly what Klipper uses (e.g. `lane0`, not `mcu_lane0`)
6. **`i2c_address`** — is `36` (hex `0x24`) unless you changed the address pads
7. **MCU firmware** — rebuilt and flashed to match the host Klipper version

Then try:
```gcode
NFC GATE=0 INIT=1
```

Still failing? Go to [Expert: Low-Level I2C Debugging](../shared/expert-low-level-i2c-debugging.md).

---

## PN7160 Not Responding

PN7160 startup problems are usually address, bus, or reset related.

### `connect_nci failed: I2C label=CORE_RESET status=START_NACK`

The MCU could not start an I2C transaction with the PN7160 while sending the
NCI `CORE_RESET` command. In practice this means the PN7160 did not answer on
the configured I2C bus.

Common causes:

- SDA/SCL wiring is disconnected, swapped, or on the wrong MCU pins.
- `i2c_mcu`, `i2c_bus`, or `i2c_address` does not match the hardware.
- The PN7160 is not powered, does not share ground with the MCU, or is held in
  reset.
- The PN7160 is stuck after a failed debug run, forced Klipper stop, or bus
  error.

After checking wiring and config, run:

```gcode
NFC GATE=0 INIT=1
```

or for the shared reader:

```gcode
NFC_SHARED INIT=1
```

If wiring and config look correct but the PN7160 still cannot communicate, power
cycle the PN7160 module. This is especially important when `ven_pin` is not
wired, because Klipper cannot hard-reset the chip without removing power.

Check in this order:

1. **`reader_type`** - the lane/shared section must set `reader_type: pn7160`.
2. **`i2c_address`** - must match the hardware address selection and be one of `40`, `41`, `42`, or `43`.
3. **`i2c_mcu` name** - must match an existing Klipper `[mcu ...]` section.
4. **SDA/SCL not swapped** - verify the selected bus pins.
5. **Power and ground** - confirm the module is powered and shares ground with the MCU.
6. **Bus type** - hardware I2C is recommended. Software I2C is supported, but consumes more MCU time.
7. **VEN state** - if `ven_pin` is wired, confirm the pin is correct. If VEN is not wired and the chip appears stuck, power-cycle the module.

Then try:

```gcode
NFC GATE=0 INIT=1
```

or for the shared reader:

```gcode
NFC_SHARED INIT=1
```

If the PN7160 becomes unusually warm after a failed test or forced Klipper stop,
stop testing and power-cycle it. Wiring `ven_pin` gives Klipper a reliable
hardware reset path.

---

### `Unable to obtain 'i2c_read_response' response`

Klipper asked the MCU for an I2C read and got no reply.

Most common causes:

| Cause | Fix |
|---|---|
| Stale MCU firmware | Rebuild and flash |
| PN532 in wrong mode | Check DIP switches (SPI/UART mode accepts wiggled lines but won't produce I2C responses) |
| PN532 not ready yet | Increase `transceive_delay` to `0.500` |
| SDA/SCL swapped | Swap them |
| Another I2C device stuck | Check if BME280 is holding the bus |

**Quick test:** If `INIT=1` succeeds but polling produces this error, the issue is timing. Try:
```ini
[nfc_gate]
transceive_delay: 0.500
```

If `INIT=1` fails immediately, the bus is not functional — check wiring and mode selection first.

---

## PN5180 Not Responding

PN5180 failures are usually power, SPI wiring, BUSY, or RST related. The
documented SLB connection uses nine wires: 5V, PSF 3.3V, GND, SCK, MISO, MOSI,
NSS/CS, BUSY, and RST. See [PN5180 wiring](pn5180-wiring.md) for the table.

### `invalid PN5180 health registers`

The reader returned invalid register data during initialization. Check these in
order:

1. **Both power rails** - the module needs 5V and the PSF connector's 3.3V.
2. **Ground** - PN5180 and the SLB/MMU must share GND.
3. **SPI direction** - SCK=`PB13`, MISO=`PB14`, MOSI=`PB15`, and NSS=`PA8` for
   the documented SLB wiring.
4. **Configuration** - `spi_bus: spi2_PB14_PB15_PB13`, `cs_pin: mmu:PA8`, and
   `reader_type: pn5180` must match the physical wiring.
5. **RST** - must be connected to the configured MCU output (`mmu:PC6` in the
   SLB example), not tied permanently high.

### `timeout waiting for PN5180 BUSY low`

The BUSY input stayed high longer than `pn5180_busy_timeout` (default `0.100`).
The driver resets and reinitializes the reader after this condition, but a
repeated timeout is a wiring or power fault, not a normal no-tag result.

1. Confirm PN5180 BUSY is connected to the configured input (`mmu:PB0` in the
   SLB example) and is not inverted.
2. Confirm BUSY is not shorted to 3.3V or 5V.
3. Confirm both power rails and RST are connected.
4. Run `NFC_SHARED INIT=1` for a shared reader or `NFC GATE=<n> INIT=1` for a
   lane reader after correcting the wiring.

Do not use `pn5180_command_delay`; the driver synchronizes each command from
the actual BUSY signal. For a complete wire-by-wire check, use
[PN5180 wiring](pn5180-wiring.md).

---

## BME280 Fails After PN532 Is Added

The BME280 (address `0x76`) and PN532 (address `0x24`) share the PB3/PB4 bus without conflict. If the BME280 worked before and breaks after the PN532 is connected:

| Symptom | Likely cause |
|---|---|
| BME280 fails on Klipper start | PN532 is in SPI or UART mode — it's disrupting the bus |
| BME280 works, fails after first INIT | PN532 power issue — voltage droop pulling SDA/SCL low |
| BME280 intermittent | Excessive pull-up current or marginal wiring |
| BME280 never works with PN532 connected | SDA/SCL short or wrong pin assignment |

**Quick check:** Disconnect the PN532 completely. If the BME280 recovers, the fault is physical — the PN532 is disrupting the bus. Check mode selection first.

---

## Tag Detected But No Spool Found

The hardware is working — the NFC reader read the tag. The Spoolman lookup failed.

```gcode
NFC GATE=0 POLL=1
```

Check:

1. **`spoolman_url`** — visit it in a browser from the Pi: `curl http://yourhost:7912/api/v1/spool`
2. **`spoolman_rfid_key`** — must match the extra field name in Spoolman **exactly** (case-sensitive)
3. **UID is on the spool record**, not the filament record
4. **No typos in the UID** — copy-paste from the console, don't transcribe by hand

Enable verbose logging to see the full HTTP exchange:

```ini
[nfc_gate]
debug:             2
console_output:    True
console_log_level: info
```

Restart Klipper, run `POLL=1`, and read the log.

---

## False Spool Removals

Gate declares the spool removed while it's still physically there.

**Cause:** The reader is occasionally missing reads (tag angle, vibration, RF environment), and `absent_threshold` is too low.

Default settings require 3 consecutive misses (~90s) before removal:
```ini
poll_interval:    30
absent_threshold: 3
```

If you're still getting false removals, raise the threshold:
```ini
absent_threshold: 5    ; ~150s before removal at default interval
```

---

## Happy Hare Not Updating

NFC is detecting tags and looking up spools, but Happy Hare's gate map isn't changing.

**Test the macro directly** — no hardware needed:

```gcode
_NFC_SPOOL_CHANGED GATE=0 SPOOL_ID=42 UID=04AABBCCDD
```

- **If this updates Happy Hare:** the macro is fine. The problem is upstream — a polling or Spoolman issue.
- **If this doesn't update Happy Hare:** check `nfc_macros.cfg` and Happy Hare command compatibility.

Common macro issues:

- Wrong `MMU_GATE_MAP` parameter syntax for your Happy Hare version
- Macro was accidentally deleted or commented out
- Happy Hare is in a state that rejects `MMU_GATE_MAP` (e.g. mid-print with gate locks)
- `spoolman_support: push` is not set in Happy Hare, so `SYNC=1` does nothing

---

## Diagnostic Command Summary

```gcode
NFC_STATUS                    ; all gates — current state
NFC GATE=0 STATUS         ; one gate
NFC GATE=0 INIT=1         ; re-initialize the NFC reader
NFC GATE=0 SCAN=1         ; one raw read, no state machine or Spoolman
NFC GATE=0 POLL=1         ; one complete cycle, watch for console output
```

For deeper investigation, enable expert debug mode:

```ini
[nfc_gate]
low_level_debug:   True
console_output:    True
console_log_level: info
```

Then:
```gcode
NFC GATE=0 HELP      ; lists all available debug commands
```

See [Expert: Low-Level I2C Debugging](../shared/expert-low-level-i2c-debugging.md) for the complete step-by-step manual sequence.

---

*Copyright (C) 2026 WoodWorker. Licensed under [GPL-3.0-or-later](https://www.gnu.org/licenses/gpl-3.0.html) — see [LICENSE](../../LICENSE).*

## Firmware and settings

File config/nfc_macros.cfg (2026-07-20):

# =============================================================================
# ============== EMU NFC GATE READER - HAPPY HARE INTEGRATION MACROS ===========
# =============================================================================
#
# THIS FILE IS READ ONLY
#
# This file is protected because it defines the NFC reader's interface to
# Happy Hare. Do not edit the installed nfc/nfc_macros.cfg file directly.
#
# To customize these macros, copy this file to a new file in your printer config
# (for example, nfc/nfc_macros_user.cfg), replace the nfc_macros.cfg include in
# printer.cfg with an include for your copy, and edit the copy. Do not include
# both files because they define the same macro names. Custom copies are not
# updated automatically, so review upstream macro changes when updating.
#
# Include this file from printer.cfg alongside the hardware config:
#
#   Per-lane install:
#     [include nfc/nfc_reader.cfg]
#     [include nfc/nfc_macros.cfg]
#     [include nfc/nfc_reader_hw.cfg]
#
#   Shared reader install (single NFC reader inside MMU body):
#     [include nfc/nfc_reader.cfg]
#     [include nfc/nfc_macros.cfg]
#     [include nfc/nfc_reader_shared.cfg]
#
#   Hybrid (per-lane + shared reader):
#     [include nfc/nfc_reader.cfg]
#     [include nfc/nfc_macros.cfg]
#     [include nfc/nfc_reader_hw.cfg]
#     [include nfc/nfc_reader_shared.cfg]
#
#
#
##################################### DISCLAIMER ########################################

# You, and you alone, are responsible for the correct execution of these macros and 
# gcodes. Any damage that may occur to your machine remains your responsibility. 
# Especially when executing this macro for the first few times, keep an eye on your 
# printer.

##########################################################################################
#
# =============================================================================
# =========================== PER-LANE READER MACROS ===========================
# =============================================================================
# Dispatched by nfc_gates/nfc_gate when a tag is read on a gate reader:
#
#   _NFC_SPOOL_CHANGED : GATE (int)  SPOOL_ID (int)  UID (hex string)  [AUTO_CREATED=1]
#                        [SCAN_FINISH=1] accepted for compatibility
#                        — or when Spoolman is disabled —
#                        GATE (int)  MATERIAL (str, optional)  COLOR (hex str, optional)
#                                    TEMP (int °C, optional)   UID (hex string)
#                                    [SCAN_FINISH=1] accepted for compatibility
#   _NFC_SPOOL_REMOVED : GATE (int)
#   _NFC_TAG_NO_SPOOL  : GATE (int)  UID (hex string)  [SPOOLMAN_DISABLED=1]
#                        [SCAN_FINISH=1] accepted for compatibility
#   _NFC_SCAN_UNRESOLVED : GATE (int)
#
# Integration model:
#   NFC_Manager reads the tag UID, asks SpoolmanClient to resolve it to a spool,
#   then dispatches these macros.  Happy Hare's local gate map is the source of
#   truth.  MMU_GATE_MAP updates the local map; MMU_SPOOLMAN SYNC=1 pushes the
#   spool location to Spoolman ("<hostname> @ MMU Gate:<gate>").
#   _NFC_TAG_NO_SPOOL fires when a tag UID cannot be resolved to a spool.
#
# Wire per-lane scan-jog installs into Happy Hare's mmu_macro_vars.cfg:
#
#   variable_user_post_preload_extension: '_NFC_SCAN_JOG_PRELOAD'
#
#   _NFC_SCAN_JOG_PRELOAD: called by HH's user_post_preload_extension hook
#     after the pregate load. It starts NFC scan-jog on the gate supplied by
#     Happy Hare; NFC starts the configured scan-jog LED effect from Python.
#
# =============================================================================
# ========================== SHARED-ONLY READER MACRO ==========================
# =============================================================================
# Wire this into Happy Hare's mmu_macro_vars.cfg:
#
#   variable_user_post_preload_extension: '_NFC_SHARED_PRELOAD'
# This applies only when no per-lane readers are configured. The hook selection
# section below describes the hybrid alternative.
#
#   _NFC_SHARED_PRELOAD: called by HH's user_post_preload_extension hook after
#     the pregate load.  Validates and commits the staged spool ID.  Safe to
#     leave wired for all loads — it skips while printing and emits an advisory
#     when no spool is pending.
# =============================================================================

# =============================================================================
# ========================= PRELOAD HOOK SELECTION ============================
# =============================================================================
# Select one hook for _MMU_SEQUENCE_VARS.variable_user_post_preload_extension:
#
#   _NFC_SCAN_JOG_PRELOAD  Per-lane readers only. Starts scan-jog on the
#                          loaded gate.
#   _NFC_SHARED_PRELOAD    Shared reader only. Commits the tag staged on the
#                          shared reader to the loaded gate.
#   _NFC_HYBRID_PRELOAD    Per-lane and shared readers together. A configured
#                          lane reader scans first; its final no-tag result
#                          falls back to staged shared-reader data. Gates with
#                          no lane reader use the shared reader directly.
#
# The hook wrapper adds SOURCE=AUTO internally for the trusted Happy Hare
# scan-jog call. Do not append SOURCE=AUTO to the configured hook name.
# =============================================================================

[gcode_macro _NFC_SCAN_JOG_PRELOAD]
description: Called by Happy Hare post-preload hook — starts per-lane NFC scan-jog
# Wire this into Happy Hare's _MMU_SEQUENCE_VARS for per-lane readers:
#   variable_user_post_preload_extension: '_NFC_SCAN_JOG_PRELOAD'
#
# Happy Hare V3 appends GATE=<n>; V4 invokes this hook without parameters, so
# the macro falls back to Happy Hare's current selected gate.
#
# SOURCE=AUTO tells NFC this call comes from Happy Hare's own hook. It permits
# Happy Hare v4's action=checking post-preload state through the version-aware
# scan-safe check. Do not add SOURCE=AUTO to manual/console invocations of
# JOG_SCAN=1.
gcode:
    {% if params.GATE is defined %}
        {% set gate = params.GATE | int %}
    {% else %}
        {% set gate = printer.mmu.gate | default(-1) | int %}
    {% endif %}

    {% set num_gates = printer.mmu.num_gates | default(0) | int %}

    {% if gate < 0 or (num_gates > 0 and gate >= num_gates) %}
        { action_raise_error("NFC post-preload could not determine Happy Hare gate. GATE param missing and printer.mmu.gate=%d" % gate) }
    {% endif %}
    NFC GATE={gate} JOG_SCAN=1 SOURCE=AUTO{% if params.SHARED_FALLBACK | default(0) | int %} SHARED_FALLBACK=1{% endif %}

[gcode_macro _NFC_SPOOL_CHANGED]
description: Called by nfc_gates/nfc_gate when a spool NFC tag is placed on a gate
gcode:
    {% set gate     = params.GATE | int %}
    {% set reader   = params.READER | default('Lane' ~ gate) %}
    {% set uid      = params.UID | default('') %}
    {% if params.SPOOL_ID is defined %}
        {% set spool_id     = params.SPOOL_ID | int %}
        {% set auto_created = params.AUTO_CREATED | default(0) | int %}
        { action_respond_info('<span style="color:lightgreen">[OK]</span> NFC[%s]: spool %d detected (UID %s)%s. Sending to Happy Hare.' % (reader, spool_id, uid, " [new spool]" if auto_created else "")) }
        {% if auto_created %}
            MMU_SPOOLMAN REFRESH=1 QUIET=1
        {% endif %}
            MMU_GATE_MAP GATE={gate} SPOOLID={spool_id} AVAILABLE=1 SYNC=1 QUIET=1
    {% else %}
        {% set name     = params.NAME     | default('') %}
        {% set material = params.MATERIAL | default('') %}
        {% set color    = params.COLOR    | default('') %}
        {% set brand    = params.BRAND    | default('') %}
        {% set min_temp = params.MIN_TEMP | default('') %}
        {% set temp     = params.TEMP     | default('') %}
        {% set diameter = params.DIAMETER | default('') %}
        {% set weight   = params.WEIGHT   | default('') %}
        { action_respond_info('<span style="color:lightgreen">[OK]</span> NFC[%s]: tag metadata detected (UID %s) — no Spoolman. brand=%s name=%s material=%s color=%s min=%s max=%s dia=%smm weight=%sg' % (reader, uid, brand, name, material, color, min_temp, temp, diameter, weight)) }
        MMU_GATE_MAP GATE={gate}{% if name %} NAME={name}{% endif %}{% if material %} MATERIAL={material}{% endif %}{% if color %} COLOR={color}{% endif %}{% if temp %} TEMP={temp | int}{% endif %} AVAILABLE=1 QUIET=1
    {% endif %}
    MMU_GATE_MAP GATE={gate} APPLY=1 QUIET=1
    MMU_SPOOLMAN SYNC=1 QUIET=1
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

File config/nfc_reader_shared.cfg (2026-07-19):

# =============================================================================
# =================== EMU NFC GATE READER - SHARED NFC HARDWARE ================
# =============================================================================
# This file configures the optional shared NFC reader mounted inside the MMU
# body, not tied to any specific lane. The default reader_type is pn532; set
# reader_type: pn7160 for PN7160 hardware, rc522 for RC522 SPI hardware, or
# pn5180 for PN5180 SPI hardware.
#
# =============================================================================
# =========================== WHY A SEPARATE FILE ==============================
# =============================================================================
# The shared reader lives in its own file so it can be added to any install
# without touching nfc_reader_hw.cfg.  Per-lane readers stay in
# nfc_reader_hw.cfg; the shared reader lives here.  For a hybrid install you
# just add one more [include] line — no merging, no commenting out sections.
#
# =============================================================================
# =============================== HOW TO USE ===================================
# =============================================================================
# Pure shared-reader install (no per-lane readers) — replace nfc_reader_hw.cfg:
#   [include nfc/nfc_reader.cfg]
#   [include nfc/nfc_macros.cfg]
#   [include nfc/nfc_reader_shared.cfg]
#
# Hybrid install (per-lane readers + shared reader) — add alongside:
#   [include nfc/nfc_reader.cfg]
#   [include nfc/nfc_macros.cfg]
#   [include nfc/nfc_reader_hw.cfg]
#   [include nfc/nfc_reader_shared.cfg]
#
# =============================================================================
# ================================ WORKFLOW ====================================
# =============================================================================
# Shared-reader-only workflow:
# 1. Tap your spool tag on the shared reader. NFC stages either a Spoolman spool
#    ID or parsed tag metadata for the next preload.
# 2. Drop the spool into an MMU lane and push the filament to the pregate sensor.
# 3. Happy Hare fires user_post_preload_extension -> _NFC_SHARED_PRELOAD ->
#    NFC_SHARED PRELOAD_CHECK/COMMIT validates the staged data, assigns it to
#    the loaded gate, then clears the one-shot staging cache.
#
# Hybrid workflow (per-lane readers + this shared reader):
# 1. Tap the spool on the shared reader to stage its spool ID or metadata.
# 2. After preload, _NFC_HYBRID_PRELOAD always starts the configured lane
#    reader scan-jog first, so it can identify the tag physically installed in
#    that gate.
# 3. If the lane reader reaches its final no-UID result, it rewinds and then
#    applies still-valid staged shared-reader data to that same gate. This is
#    useful when the lane reader cannot read a tag type supported by the shared
#    reader, such as an ISO15693 tag staged with a PN5180.
# 4. A gate without a configured lane reader uses the staged shared-reader data
#    directly. If no shared data is staged, no NFC assignment is made.
#
# While data is staged, the shared reader continues lightweight UID polling.
# Repeated probes of the same UID skip rich payload reads and retain the staged
# result. A different UID immediately clears staged data, then triggers a new
# full read. A successful result starts a new pending timeout.
#
# Wire the Happy Hare post-preload hook in mmu_macro_vars.cfg:
#   variable_user_post_preload_extension: '_NFC_SHARED_PRELOAD'
# This is for a shared-reader-only installation. If this printer also includes
# nfc_reader_hw.cfg for per-lane readers, use this instead:
#   variable_user_post_preload_extension: '_NFC_HYBRID_PRELOAD'
# Do not use NFC JOG_SCAN=1 directly as the hook.
#
# =============================================================================
# ================================ HARDWARE ====================================
# =============================================================================
# Run install.sh to fill in hardware values automatically, or edit reader_type
# and the matching I2C or SPI settings below to match your wiring. RC522 and
# PN5180 use SPI settings instead of i2c_bus and i2c_address. PN5180 requires
# reset_pin and busy_pin, plus both 5V and PSF 3.3V power. See
# docs/i2c-nfc/pn5180-wiring.md for the nine-wire SLB example.
#
# [WARN] After updating Klipper, rebuild and flash the MCU hosting the NFC reader.
#    The MCU must be on the same Klipper version as the host.
#
# Full setup guide: docs/shared/shared-reader.md
# =============================================================================
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

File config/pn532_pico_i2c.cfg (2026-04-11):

# =============================================================================
# EMU NFC Gate Reader — Hardware Configuration (I2C / PN532 / Pico)
# =============================================================================
# Use this config when you have PN532 modules wired to a dedicated Raspberry
# Pi Pico over I2C — NOT to EBB42 lane boards.
#
# Use nfc_gate_i2c_pn532.cfg instead if your PN532 modules are wired to
# EBB42 lane boards.  The two configs are mutually exclusive.
#
# Include BOTH files from printer.cfg:
#   [include nfc_vars.cfg]          ← user settings (Spoolman URL etc.)
#   [include nfc_macros.cfg]
#   [include nfc_gates_i2c_pn532_pico.cfg]
#
# Integration model — UID lookup
# ────────────────────────────────────────────
# Tags are NEVER written to.  Stick any blank 13.56 MHz NFC tag on each spool.
# For each spool, read its tag UID with your phone and paste it into the "rfid"
# extra field on the matching Spoolman spool record.
# See docs/shared/spoolman-integration.md for step-by-step instructions.
#
# Required install steps (do these once):
#   1. Clone the repo and run install.sh — see Readme.md for the one-liner.
#   2. Flash standard Klipper MCU firmware to the Pico with CAN bus support
#      (see docs/spi-rc522/setup.md for make menuconfig settings — same Pico
#       firmware regardless of whether you use SPI or I2C readers).
#   3. Find the Pico's CAN UUID and fill in canbus_uuid below:
#        ~/klippy-env/bin/python ~/klipper/scripts/canbus_query.py can0
#   4. Wire PN532 modules to the Pico I2C bus — see docs/i2c-pn532/wiring.md.
#   5. Set each PN532 to I2C mode (onboard DIP switch or solder jumper).
#   6. Set unique I2C addresses for each reader (see PN532 address note below).
#   7. Fill in gate_i2c_addresses below to match.
#   8. Set your Spoolman URL in nfc_vars.cfg.
#   9. Restart Klipper:  sudo systemctl restart klipper
#
# PN532 I2C address note
# ──────────────────────
# In I2C mode the PN532's address is set by two ADDR pins (A0, A1):
#
#   A1=0  A0=0  →  0x24  (default — most modules ship with both low)
#   A1=0  A0=1  →  0x25
#   A1=1  A0=0  →  0x26
#   A1=1  A0=1  →  0x27
#
# Not all breakout boards expose these pins.  If yours does not, all readers
# will share the same address (0x24) and MUST be on different I2C buses.
# The Pico has two hardware I2C buses (i2c0, i2c1).  For more than 2 readers
# with non-addressable modules, use PN532 modules that expose ADDR pins.
#
# Driver:   pn532_driver.PN532Driver  (ISO14443A via InListPassiveTarget)
# Manager:  NFCGateManager (one shared thread, sequential gate polling)
# Macros:   nfc_macros.cfg (shared with all paths — include separately)
# =============================================================================


# -----------------------------------------------------------------------------
# [mcu nfc_pico] — Raspberry Pi Pico as a CAN bus MCU
# -----------------------------------------------------------------------------
# Firmware build settings (make menuconfig) — same as SPI/RC522 Pico path:
#   Micro-controller:        Raspberry Pi RP2040
#   Communication interface: CAN bus
#   CAN TX GPIO:             4   (SN65HVD230 CAN transceiver)
#   CAN RX GPIO:             5   (SN65HVD230 CAN transceiver)
#   CAN bus speed:           1000000
# -----------------------------------------------------------------------------
[mcu nfc_pico]
canbus_uuid: YOUR_UUID_HERE


# -----------------------------------------------------------------------------
# [nfc_gates] — PN532 readers over I2C on the Pico
# -----------------------------------------------------------------------------
# gate_i2c_addresses tells the manager to use the I2C/PN532 path.
# Without this key the manager falls back to SPI/RC522 mode.
#
# List one address per gate, in gate order (gate 0 first), comma-separated.
# Addresses can be decimal (36) or hex (0x24) — both are accepted.
#
# Example: 4 readers with unique addresses on a single I2C bus
#   gate 0 → PN532 at 0x24  (A1=0, A0=0)
#   gate 1 → PN532 at 0x25  (A1=0, A0=1)
#   gate 2 → PN532 at 0x26  (A1=1, A0=0)
#   gate 3 → PN532 at 0x27  (A1=1, A0=1)
#
# Pico I2C0 hardware pins (default):
#   SCL = GP1    SDA = GP0
# Pico I2C1 hardware pins:
#   SCL = GP3    SDA = GP2   (or GP7/GP6 — check RP2040 GPIO mux table)
# -----------------------------------------------------------------------------
[nfc_gates]

# I2C bus on the Pico — defines SCL/SDA pins for the primary I2C bus
i2c_mcu:   nfc_pico
i2c_bus:   i2c0         # hardware I2C0: SCL=GP1, SDA=GP0

# One address per gate, in gate order.
# Adjust to match the ADDR pin settings on your PN532 modules.
gate_i2c_addresses: 0x24, 0x25, 0x26, 0x27

# I2C speed — 400 kHz is standard fast-mode; reduce to 100000 if unstable
i2c_speed: 400000

# ── User settings ─────────────────────────────────────────────────────────────
# Spoolman URL, polling, thresholds, and debug level are set in nfc_vars.cfg.
# Copy any key here only if you need a value that differs from nfc_vars.cfg.
#
# Defaults (from nfc_vars.cfg):
#   spoolman_url      http://mainsailos.local:7912
#   spoolman_rfid_key rfid
#   poll_interval     30
#   absent_threshold  3
#   debug             1
#
# PN532 I2C timing (shared with EBB42 path, set in nfc_vars.cfg):
#   transceive_delay  0.250   — wait after InListPassiveTarget command
#   crc_delay         0.050   — wait after InRelease command

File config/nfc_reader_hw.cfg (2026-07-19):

# =============================================================================
# ================= EMU NFC GATE READER - NFC I2C LANE HARDWARE ================
# =============================================================================
# Supported documented path:
#   one NFC reader module per lane MCU / EBB42 board.
#   PN532 is the default reader; PN7160, RC522, and PN5180 may be selected per
#   lane with reader_type. SPI readers need spi_bus and cs_pin; PN5180 also
#   requires BUSY and RST. See docs/i2c-nfc/pn5180-wiring.md for the SLB setup.
#
# Include after nfc_reader.cfg and nfc_macros.cfg:
#   [include nfc/nfc_reader.cfg]
#   [include nfc/nfc_macros.cfg]
#   [include nfc/nfc_reader_hw.cfg]
#
# The base [nfc_gate] section in nfc_reader.cfg defines defaults for all
# lanes. Each [nfc_gate laneN] section below inherits those keys automatically.
# Override a key in a lane section only when that lane needs a different value.
# Example:
#   [nfc_gate]
#   reader_type: pn532
#   i2c_address: 36
#   i2c_bus:     i2c3_PB3_PB4
#   scan_enabled: False
#
#   [nfc_gate lane1]
#   mmu_gate:     1
#   i2c_mcu:      lane1
#   reader_type:  pn532
#   scan_enabled: True
#
# Address note:
#   PN532 has a fixed I2C address, so lanes normally inherit i2c_address: 36
#   from the base [nfc_gate] section.
#
#   PN7160 can use multiple I2C addresses selected by hardware address pins or
#   DIP switches. In the common EMU layout, each lane has its own MCU/I2C bus,
#   so all PN7160 lanes may use the same inherited address. If multiple PN7160
#   readers share one MCU/I2C bus, give each reader a unique i2c_address in its
#   [nfc_gate laneN] section, for example:
#
#     reader_type:  pn7160
#     i2c_address:  40     # 0x28; other PN7160 addresses may be 41-43
#
# RC522 note:
#   RC522 can be used per lane if that lane section provides Klipper SPI
#   settings (`cs_pin`, `spi_bus`/software SPI pins) instead of
#   i2c_address/i2c_bus.
#   See nfc_reader_shared.cfg for a copyable RC522 shared-reader example.
#
#   Example RC522 lane override:
#
#     [nfc_gate lane1]
#     enabled:      True
#     mmu_gate:     1
#     i2c_mcu:      mmu1
#     reader_type:  rc522
#     cs_pin:       mmu1:PA4
#     spi_bus:      spi1
#     spi_speed:    500000  # hardware SPI default; use 100000 for software SPI
#     #rc522_transceive_delay: 0.035
#
# Each [nfc_gate laneN] section maps:
#   Happy Hare gate number -> Klipper lane MCU -> NFC reader hardware.
# startup_poll_delay staggers automatic startup polling so all readers do not
# enter their first poll cycle at the same time.
# Each [mmu_nfc_endstop laneN] section seeds Happy Hare with a homeable virtual
# endstop that uses the matching lane reader. Use ENDSTOP=nfc_laneN in Happy
# Hare homing/test moves.
#
# Happy Hare V4 / multi-unit example:
#   Section names are labels only. The nfc_gate reference binds the virtual
#   endstop to its reader, while mmu_gate is Happy Hare's global gate number.
#   For example, the first physical lane of unit0 can be configured as:
#
#     [nfc_gate unit0_lane0]
#     enabled:                True
#     mmu_gate:                0
#     i2c_mcu:                 unit0_gate0
#     startup_poll_delay:      0.0
#
#     [mmu_nfc_endstop unit0_lane0]
#     nfc_gate:                unit0_lane0
#     endstop_name:            nfc_unit0_lane0
#     poll_interval:           0.05
#     register_sensor:         True
#
#   A second unit's first lane might use mmu_gate: 4. Happy Hare V4 resolves
#   that global gate to the correct unit drive automatically.
# Set enabled: False on a lane to keep the template in place without creating
# the I2C reader, registering the GCode mux command, or initializing hardware.
#
# i2c_mcu: is consumed by Klipper's I2C bus layer (MCU_I2C_from_config),
# not read explicitly by the plugin.  The MCU name must already exist in
# Klipper / Happy Hare config.  Example: [mcu lane0], [mcu lane1], etc.
#
# [WARN] After updating Klipper, rebuild and flash the lane MCU / EBB42 firmware.
# Updating the host alone is not enough for NFC reader I2C troubleshooting.
# =============================================================================

# =============================================================================
# ================================= LANE 0 =====================================
# =============================================================================
[nfc_gate lane0]
enabled:                True
mmu_gate:                0
i2c_mcu:                 mmu0
startup_poll_delay:      0.0

[mmu_nfc_endstop lane0]
nfc_gate:                lane0
endstop_name:            nfc_lane0
poll_interval:           0.05
register_sensor:         True
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

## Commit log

2026-03-18 fixed log path, added Klippy.log path to log file
    [nfc_vars.cfg]
2026-04-11 NFC_GATE_STATUS cross-references MMU lane MCUs from Klipper registry
    Instead of only listing configured NFC gates, the command now enumerates
    all lane<N> MCUs registered in Klipper (same source HH uses via
    [board_pins lane]) and shows one row per lane:
    - configured lane → spool/UID status as before
    - unconfigured lane → "no NFC reader configured"
    Falls back to the old plain list when no lane MCUs are found (non-MMU
    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
2026-04-11 fix mcu.py recursive send crash in _wake_pn532
    Two sequential i2c_read calls per wake attempt caused Klipper's MCU
    command system to re-enter send→_do_send recursively when the PN532
    NACKed the first read, blowing the Python call stack.
    Revert to a single i2c_write + i2c_read per attempt (same pattern as
    the rest of the driver). The STATUS byte is the first byte of the
    15-byte read, parsed by _check_frame as before. Increased post-TX
    wait to 150 ms on the first attempt (cold-start) and 75 ms thereafter,
    with a 50 ms gap between attempts.
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2026-04-11 reverting to i2C write/read with polling
2026-04-11 redid configs and pn532 SPI driver
    [pn532_i2C.cfg, pn532_pico_i2c.cfg, pn532_spi.cfg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]
2026-04-13 changed nfcgate initi to post to the printer instead of grabbing gcode
2026-04-13 changed from hh context and next spool_id to mmu gate map because the gate has to be set
    [nfc_macros.cfg]
2026-04-13 updated to use spoolman macros instead of gatemap macros
    [nfc_macros.cfg, nfc_vars.cfg]
2026-04-15 changed klipper commands and macros to conform to HH command archtypes
    [nfc_macros.cfg]
2026-04-19 cleaned up logging to rotate log files
    [nfc_vars.cfg]
2026-04-20 Adding mounting bracket for PN532
    [LED_holder_with_NFC.step]
2026-04-20 NFC Bracket as STL
    [LED_holder_with_NFC.stl]
2026-04-24 removed old step and stl files
    [LED_holder_with_NFC.step, LED_holder_with_NFC.stl]
2026-04-24 exposed spin-jog variables in the config file
    [nfc_vars.cfg]
2026-04-25 documented scan interval on the scan-jog.
    [nfc_vars.cfg]
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2026-04-26 testing fix from klipper crash, timer too close
2026-04-26 updating out of the box config
    [nfc_vars.cfg]
2026-04-26 comment in config file
    [nfc_vars.cfg]
2026-04-29 implementation of mmu_vars.cfg and blocking scans when any spool is not parked
    [nfc_vars.cfg]
2026-04-30 changed default scan_job_mm
    [nfc_reader.cfg]
2026-05-01 cleaning up config and documentation
    [nfc_macros.cfg, nfc_reader.cfg, nfc_reader_hw.cfg]
2026-05-01 integrating lameandboard
    [nfc_macros.cfg]
2026-05-04 working version of create vendor filament and spool
    [nfc_macros.cfg]
2026-05-05 added a swell post jog, give reader a chance to read. Added milliseconds to the logger
    [nfc_reader.cfg]
2026-05-05 tightening up the install and highlighting defaults
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2026-05-09 Use Happy Hare unload gate step command
    [nfc_reader.cfg]
2026-05-09 finshed implementing the resetting of caches and catching the no tag fall through
    [nfc_manager.py]
2026-05-12 Restore scan-jog rewind buffer parking
    This restores the behavior that was previously introduced in commit f4d98b6 (Improve scan-jog rewind parking). That change added scan_rewind_buffer_mm so NFC would only fast-rewind to a configured buffer distance, then hand the final parking move back to Happy Hare.
    After the upstream merge, run_rewind regressed to a hard-coded 10mm buffer and called mmu_check_gate. That made settings such as scan_rewind_buffer_mm: 150 ineffective: a 220mm scan still rewound about 210mm instead of leaving 150mm for the final gate parking step.
    Compute the fast rewind as scan_mm_total - scan_rewind_buffer_mm, skip the fast rewind when the scan distance is already insid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
2026-05-13 tightening up the logging messages and aligning to klipper:respond methods
    [nfc_macros.cfg, nfc_reader_hw.cfg, nfc_reader_shared.cfg]
2026-05-13 tightening up messaging and logging
    [nfc_manager.py]
2026-05-14 implementation of left-lane-interference with logging levels. ready for testing
    [nfc_manager.py]
2026-05-14 added the _nfc_gate_clear_cache macro to the base macros file, it is called at the beginining for the scan jog, clears the HH gate_map cache from the previous attributes, and only sets them again if 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
    [nfc_macros.cfg]
2026-05-18 Sync from private repo
    [nfc_macros.cfg, nfc_reader_hw.cfg, nfc_reader_shared.cfg]
2026-06-20 initial implementation of continuous motion scan_jog
    [nfc_reader.cfg]
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2026-06-20 changing the continuous read completely. using the python path instead of the macro path, and using the sync(gear_only) /move() low level calls.
    [nfc_reader.cfg]
2026-06-20 fixing console HELP menu
    [nfc_manager.py]
2026-06-20 cleaning console messaging in macros
    [nfc_macros.cfg]
2026-07-15 added an endstop merge in the installer, and changed NFC_DOCTOR to do a check, then offer option to repair the virtual endstop section.
2026-07-15 fixed nfc_doctor virtual endstop ingection code
    [nfc_manager.py]
2026-07-17 modified the LED release to do a per lane release right as the fast rewind ends. handing control back over to Happy Hare for the final park sequence
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2026-07-18 Add EMU NFC reader LED holder models
    Add printable STL and editable STEP sources for EMU NFC reader LED holders.
    Replace the legacy Bambu-height-only STEP source with the renamed EMU PN532 v3 assets, and document the bundled models in the README.
    [LED_holder_for_EMU_NFC_Reader_Board.step, LED_holder_for_EMU_NFC_Reader_Board.stl, LED_holder_v3_for_EMU_PN532.step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]
2026-07-19 Support metadata-only shared reader preload
    Treat a fully parsed tag without a Spoolman ID as a valid shared-reader result instead of an unresolved UID. Shared readers now stage a metadata pending result with the same timeout, replacement, LED ownership, polling pause, and cancellation lifecycle used for staged Spoolman spools.
    Extend the Happy Hare post-preload bridge to approve metadata pending results and commit them to the actual hook gate. The commit dispatches the existing _NFC_SPOOL_CHANGED metadata path asynchronously, preserving the established value sanitization and MMU_GATE_MAP behavior used by per-lane readers while avoiding NEXT_SPOOLID, which only accepts integer Spoolman IDs.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
    [nfc_macros.cfg]
2026-07-19 Stage shared metadata reads from gate state
    GateState intentionally emits metadata-only reads as EVENT_CHANGED with spool=None so ordinary event consumers do not receive an object sentinel in the event tuple. The DIRECT_METADATA_SPOOL marker r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
    Shared reader staging incorrectly inspected the normalized event spool, causing complete no-Spoolman rich reads such as TigerTag to be logged as changed but never retained as a pending metadata resul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
    Inspect current_spool for the metadata sentinel instead. This restores the pending metadata lifecycle and lets the existing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
2026-07-19 Clear stale shared-reader metadata on untagged preload
    When the shared reader has no pending spool or metadata, its post-preload hook previously only reported the missing staged tag. Happy Hare consequently retained NAME, MATERIAL, COLOR, and temperature from an earlier shared-reader assignment on the newly loaded gate.\n\nClear the target gate to an available unknown state in that no-pending branch. This mirrors the visible-state behavior of an unresolved lane scan while preserving the lane-reader route and both staged shared-reader commit paths.
    [nfc_macros.cfg]
2026-07-19 Separate preload hooks by NFC reader layout
    Split the former routing _NFC_SHARED_PRELOAD hook into explicit installation-mode entry points. _NFC_SCAN_JOG_PRELOAD remains the per-lane hook, _NFC_SHARED_PRELOAD now handles shared-reader-only ins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
    [nfc_macros.cfg, nfc_reader.cfg, nfc_reader_hw.cfg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]
2026-07-19 Clarify shared preload staging behavior
    Document both shared-reader post-preload outcomes next to force_spool_id. A staged Spoolman spool or parsed metadata is assigned to the loaded gate; without a staged tag, NFC assignment is skipped and stale gate metadata is cleared.\n\nClarify that the setting chooses the no-tag advisory message only. It cannot block physical preload because validation runs from Happy Hare's post-preload hook.
    [nfc_reader_shared.cfg]
2026-07-19 Document hybrid reader fallback workflow
    Expand the shared-reader template workflow with separate shared-only and hybrid flows. Document that hybrid preload always scans a configured lane reader first, then applies valid staged shared-reade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
    [nfc_reader_shared.cfg]
2026-07-19 Keep shared startup polling active after pending timeout
    A shared reader configured with startup_polling=1 incorrectly resumed through the timed READ/REPLACE path after a staged tag expired. After the 60-second pending timeout, it would therefore stop polling again after shared_read_timeout.\n\nResume startup polling with no read deadline. Retain the timed deadline only for manual READ/REPLACE sessions, where bounded scanning remains intentional.
    [nfc_manager.py]
2026-07-19 Keep shared reader polling while a tag is staged
    Do not stop shared-reader polling for the entire pending_spool_id_timeout after a successful rich read. Keep the staged spool or metadata eligible for preload and hybrid fallback, while continuing lightweight UID probes.\n\nA repeated UID now skips rich payload reads and logs the suppression at debug level 3. This avoids repeatedly reading NTAG payloads or authenticated Bambu/MIFARE blocks while the same tag remains on the shared reader.\n\nWhen the UID changes, immediately clear the prior staged data and its LED state before attempting a full read of the new tag. A complete new read establishes a fresh pending timeout; an incomplete new read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
    [nfc_reader_shared.cfg]
2026-07-20 Make nfc_macros.cfg read-only and add a test scaffold
    nfc_macros.cfg now installs as a symlink to the repo's shipped copy,
    matching how Happy Hare treats its own macro files, instead of being
    merge-installed like the other config files.
    - install.sh: new install_managed_macros() replaces the merge_config()
    call for nfc_macros.cfg. On first run against an existing install it
    backs up any regular file to nfc_macros.cfg.pre-managed-<timestamp>
    before creating the symlink; later runs just verify the link target
    and fix it if it's stale (e.g. pointing at an old repo checkout path).
    - config/nfc_macros.cfg: header now says the file is read-only and
    explains the fork-and-include pattern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
    [nfc_macros.cfg]
2026-07-20 updated installer with Key behavior: • A healthy existing installation exits immediately and directs users to Moonraker’s web updater.
    • An incomplete existing installation recommends install.sh -r.
    • Repair is non-interactive.
    • Repair preserves nfc_reader.cfg, lane hardware settings, shared-reader settings, and custom values.
    Repair restores Python symlinks, the read-only macro link, ordered printer.cfg includes, Moonraker configuration, and .install-state.
    • Existing editable nfc_macros.cfg files receive a timestamped backup before conversion.
    • Moonraker’s deprecated install_script hook is removed.
    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
    [nfc_macros.cfg]
